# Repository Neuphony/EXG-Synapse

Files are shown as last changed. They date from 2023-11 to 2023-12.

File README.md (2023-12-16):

<h1 id="github---readme">Github - Readme</h1>
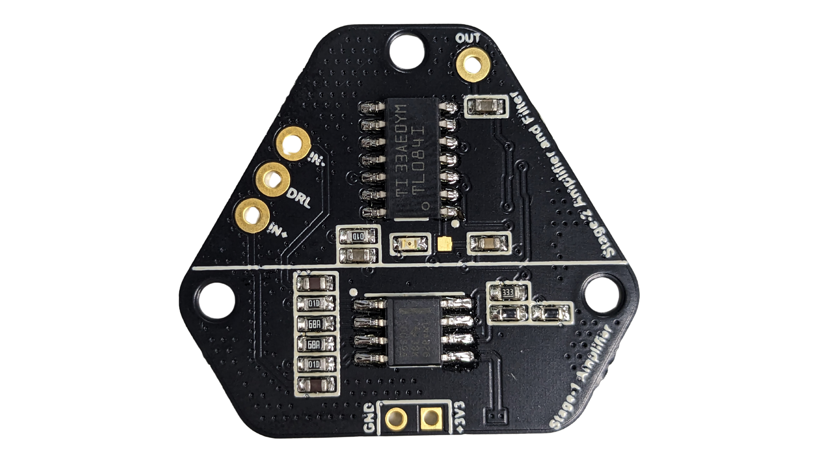
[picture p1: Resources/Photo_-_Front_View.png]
front
<p>Front View<br>        </p>
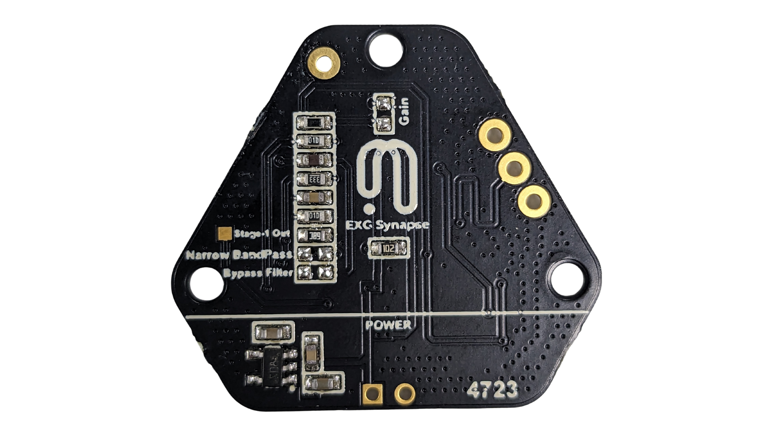
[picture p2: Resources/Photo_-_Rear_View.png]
rear
<p>Rear View<br>        </p>
<p><strong>Setup Instructions</strong></p>
<ol>
<li><p><strong>What is EXG Synapse?</strong>  </p>
<p>  Neuphony EXG Synapse is an innovative, hexagon-shaped chip designed for recording high-quality biopotential signals from various regions of the body, including the heart (ECG), brain (EEG), eyes (EOG), and muscles (EMG). Serving as a robust analog-front-end (AFE) biopotential signal-acquisition board, the Neuphony EXG Synapse can seamlessly integrate with a range of microcontroller units (MCUs) or single-board computers (SBCs) equipped with an analog-to-digital converter (ADC). Compatible platforms include popular options such as Arduino UNO &amp; Nano, Espressif ESP32 and more.</p>
</li>
<li><p><strong>Hardware Requirements</strong> :   EXG Synapse, DOIT-ESP32-DEVKIT-V1, Jumper Wires<br><strong>Software Requirements</strong> : Arduino IDE</p>
</li>
<li><p><strong>PCB Configuration</strong>  </p>
<p>  EXG Synapse has configuration options in terms of gain and bandpass filter bandwidth. The user can modify these values depending on the use case. Here is an image showing the resistor pad R9(for gain) and capacitor pad C2(for filter bandwidth).</p>
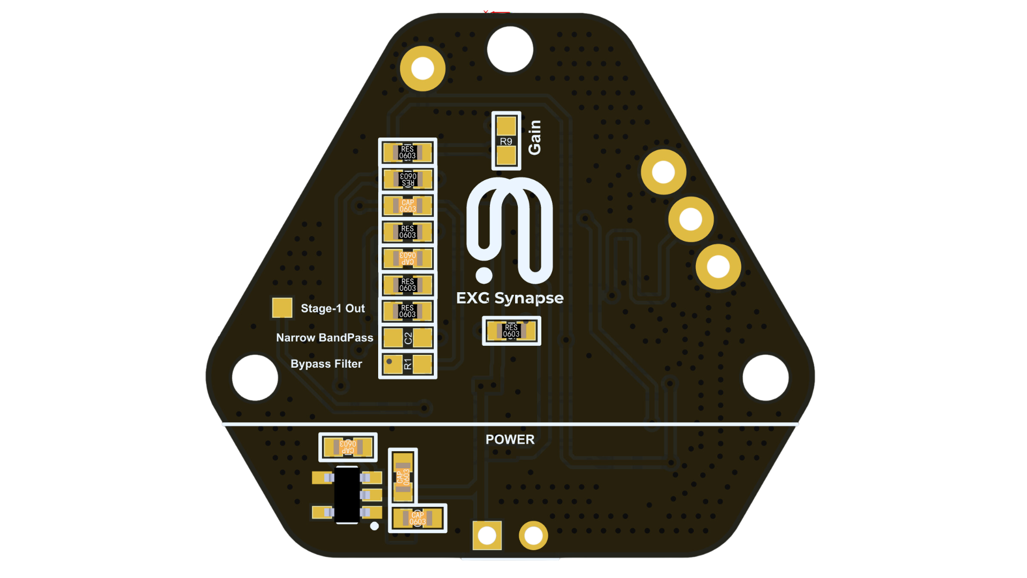
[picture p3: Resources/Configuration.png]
Configuration

</li>
<li><p><strong>Connection with ESP32</strong>  </p>
<p>  EXG Synapse requires only three wires to connect to any MCU. 3V3 connects to the 3V3 pin on the ESP32 and GND to GND pin on the ESP32. The Output of EXG Synapse can be connected to any ADC pin of ESP32 and configured as an analog input to read the data.</p>
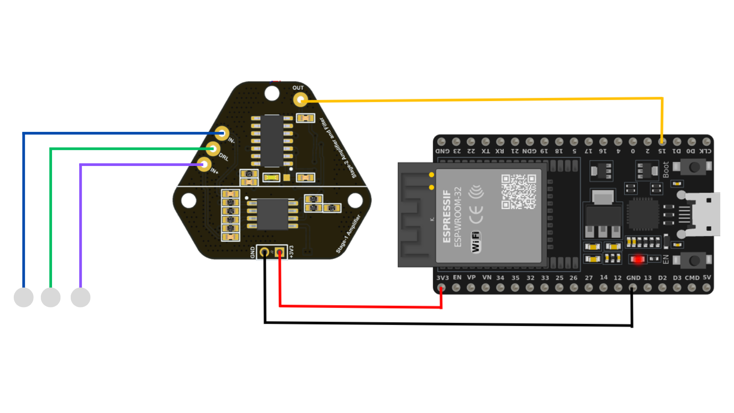
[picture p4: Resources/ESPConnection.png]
ESPConnection

</li>
<li><p><strong>Flashing Code on ESP32</strong>  </p>
<p>  To flash the required code on ESP32, you need to install Arduino IDE and setup for flashing to an ESP32. You can follow <a href="https://espressif-docs.readthedocs-hosted.com/projects/arduino-esp32/en/latest/installing.html">this guide</a> if you don’t find your board listed in Arduino. Once your board is added to Arduino, you can go to <a href="https://github.com/Neuphony/EXG-Synapse">our GitHub repository</a>, here you will find all the necessary files for acquiring the data using EXG Synapse.</p>
<p>  Navigate to the folder of your choice (serial or BLE), and download the required .ino (EEG, ECG, EMG, EOG). Now compile and upload the code on your board.</p>
<p>  Please follow the screenshots given below.</p>
<p>  <strong>Board selection:</strong></p>
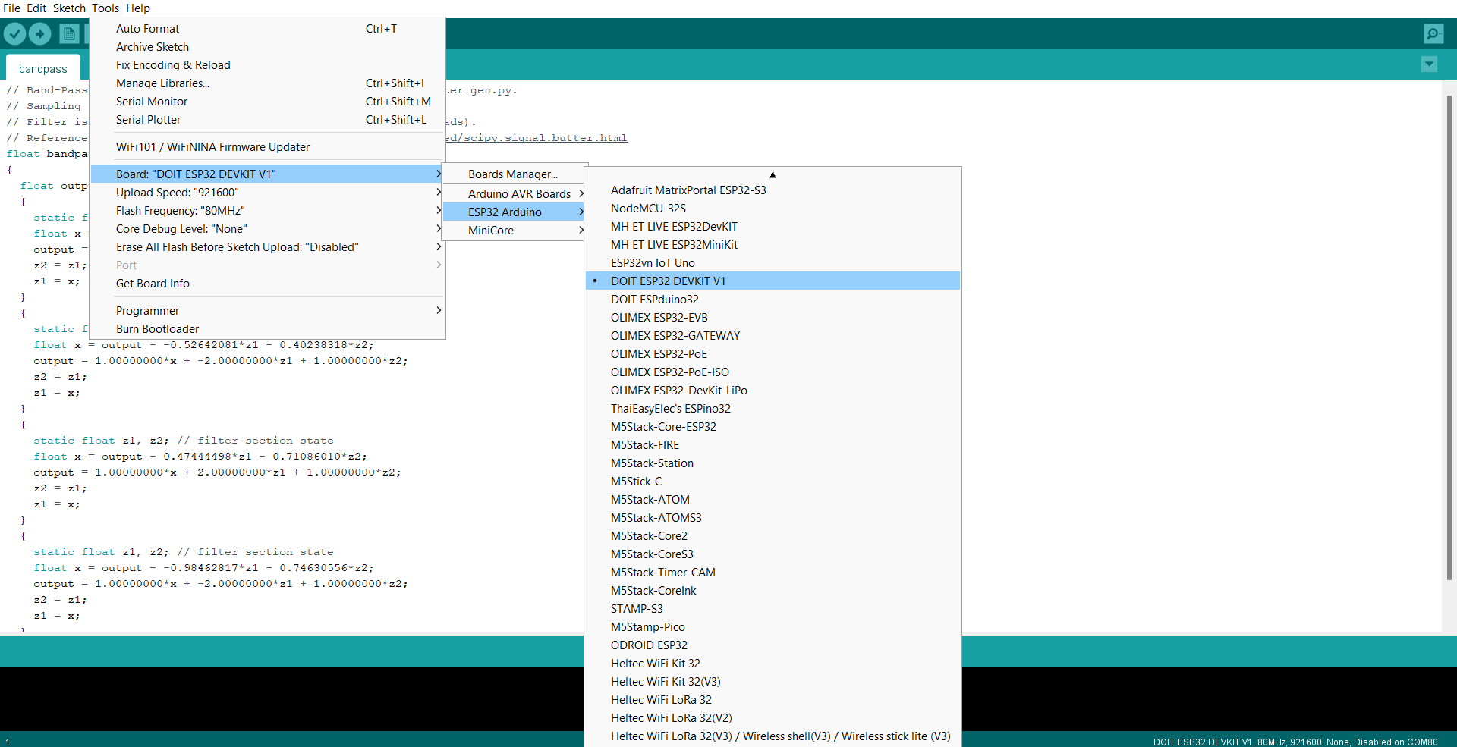
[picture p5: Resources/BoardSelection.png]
BoardSelectiond

<p>  <strong>COM Port selection:</strong></p>
<p>  BoardSelection</p>
</li>
<li><p><strong>Skin Preparation</strong>  </p>
<p>  Before placing the electrode, skin surface must be cleaned with an alcohol based wet wipe and then Nuprep Gel can be used to enhance the signal quality as it reduces the skin impedance. You can follow <a href="https://www.youtube.com/watch?v=qQSClWIYUwM&t=76s">this guide</a> on how to use Nuprep Gel while preparing for data acquisition.</p>
</li>
<li><p><strong>Data Visualization:</strong>  </p>
<p>  The Lab Streaming Layer (LSL) is a system designed for real-time data streaming and recording. We have provided a python script located in the <a href="https://github.com/Neuphony/EXG-Synapse">GitHub repository</a> used to read the data from serial and create a LSL stream. The stream created by the script can be easily visualized using a LSL-compatible software such as <strong><a href="https://pressrelease.brainproducts.com/lsl-viewer/">BrainVision LSL Viewer</a>.</strong> It can be downloaded for free using this <a href="https://www.brainproducts.com/downloads/more-software/#utilities">link</a>.</p>

# EEG

1. **What is EEG?**
EEG stands for electroencephalography, which is a non-invasive technique used to measure and record electrical activity in the brain. It involves placing electrodes on the scalp to detect and amplify the electrical signals produced by the brain. These signals, known as brainwaves, can provide insights into brain function and activity.

2. **What is EXG Synapse?**
Neuphony EXG Synapse is an innovative, hexagon-shaped chip designed for recording high-quality biopotential signals from various regions of the body, including the heart (ECG), brain (EEG), eyes (EOG), and muscles (EMG). Serving as a robust analog-front-end (AFE) biopotential signal-acquisition board, the Neuphony EXG Synapse can seamlessly integrate with a range of microcontroller units (MCUs) or single-board computers (SBCs) equipped with an analog-to-digital converter (ADC). Compatible platforms include popular options such as Arduino UNO & Nano, Espressif ESP32 and more.

3. **Hardware Requirements** : EXG Synapse, DOIT-ESP32-DEVKIT-V1, Jumper Wires
**Software Requirements** : Arduino IDE

4. **PCB Configuration:**
EXG Synapse has configuration options in terms of gain and bandpass filter bandwidth. The user can modify these values depending on the use case. Here is an image showing the resistor pad R9(for gain) and capacitor pad C2(for filter bandwidth).

    Configuration

1. **Connection with ESP32**
EXG Synapse requires only three wires to connect to any MCU. 3V3 connects to the 3V3 pin on the ESP32 and GND to GND pin on the ESP32. The Output of EXG Synapse can be connected to any ADC pin of ESP32 and configured as an analog input to read the data.

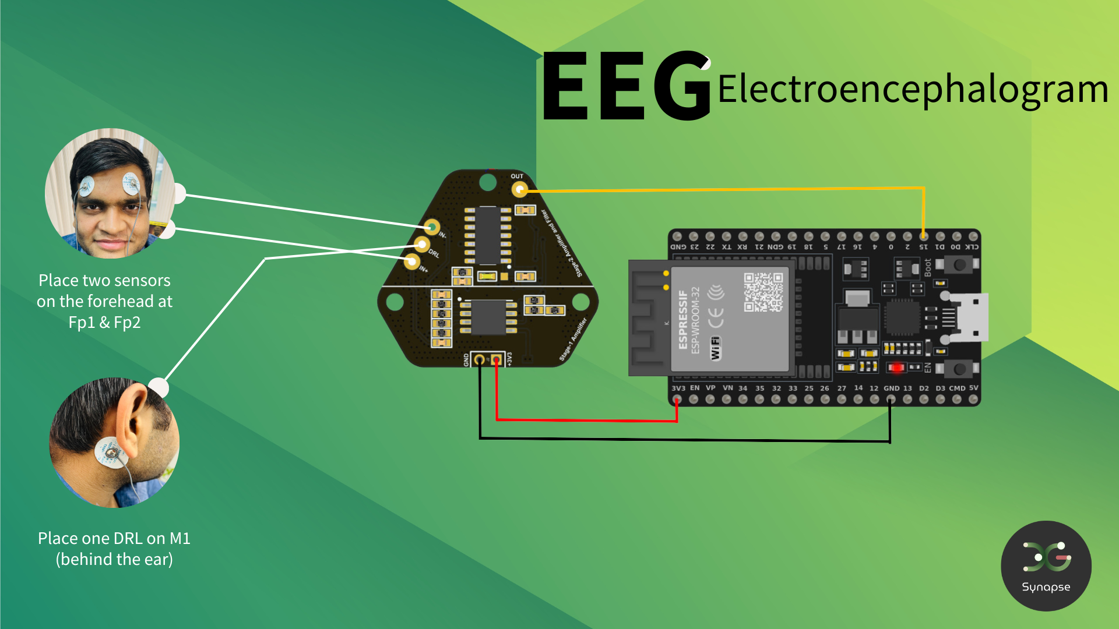
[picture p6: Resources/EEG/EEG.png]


1. **Flashing Code on ESP32**
To flash the required code on ESP32, you need to install Arduino IDE and setup for flashing to an ESP32. You can follow [this guide](https://espressif-docs.readthedocs-hosted.com/projects/arduino-esp32/en/latest/installing.html) if you don’t find your board listed in Arduino. Once your board is added to Arduino, you can go to [this GitHub repository](https://github.com/Neuphony/EXG-Synapse), here you will find all the necessary files for acquiring the data using EXG Synapse.

Navigate to the EEG folder and then to Arduino, and download required .ino file. Now compile and upload the code on your board.

2. **Skin Preparation**
Before placing the electrode, skin surface must be cleaned with an alcohol based wet wipe and then Nuprep Gel can be used to enhance the signal quality as it reduces the skin impedance. You can follow [this](https://www.youtube.com/watch?v=qQSClWIYUwM) guide on how to use Nuprep Gel while preparing for data acquisition.

3. **Electrode Placement:**
Check above image for correct electrode placement

4. **Data Visualization:**
Serial : The Lab Streaming Layer (LSL) is a system designed for real-time data streaming and recording. We have provided a python script located in the [GitHub repository](https://github.com/Neuphony/EXG-Synapse) used to read the data from serial and create a LSL stream. The stream created by the script can be easily visualized using a LSL-compatible software such as **[BrainVision LSL Viewer](https://pressrelease.brainproducts.com/lsl-viewer/).** It can be downloaded for free using this [link](https://www.brainproducts.com/downloads/more-software/#utilities).

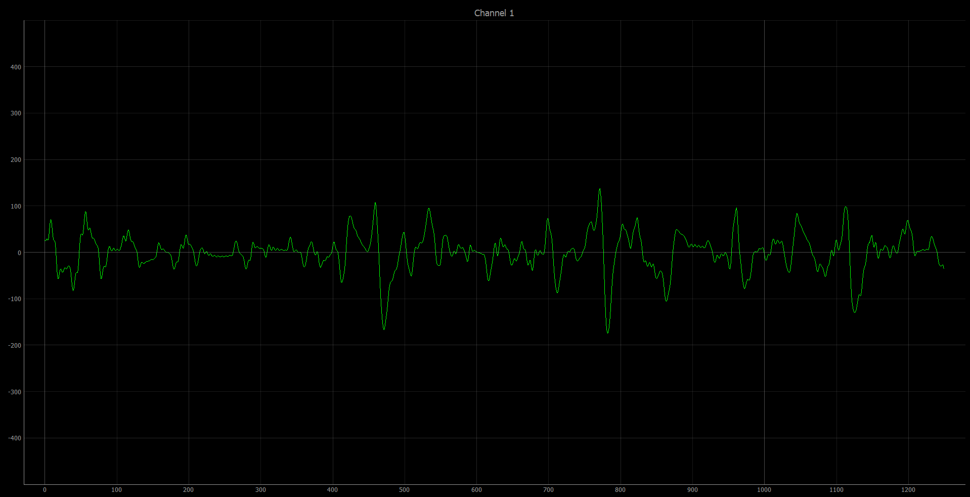
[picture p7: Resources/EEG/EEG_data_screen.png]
EEG_data_screen
    
    
    BLE : If flashed with the code provided under software\Arduino\ble, ESP32 will stream data continously over BLE. You can create a client side interface to read this data and use it for further applications.

# ECG

1. **What is ECG?**
ECG stands for Electrocardiogram. It is a medical test that measures and records the electrical activity of the heart. The ECG helps in diagnosing various heart conditions and evaluating the heart's overall health.

1. **What is EXG Synapse?**
Neuphony EXG Synapse is an innovative, hexagon-shaped chip designed for recording high-quality biopotential signals from various regions of the body, including the heart (ECG), brain (EEG), eyes (EOG), and muscles (EMG). Serving as a robust analog-front-end (AFE) biopotential signal-acquisition board, the Neuphony EXG Synapse can seamlessly integrate with a range of microcontroller units (MCUs) or single-board computers (SBCs) equipped with an analog-to-digital converter (ADC). Compatible platforms include popular options such as Arduino UNO & Nano, Espressif ESP32 and more.

2. **Hardware Requirements** : EXG Synapse, DOIT-ESP32-DEVKIT-V1, Jumper Wires
**Software Requirements** : Arduino IDE

3. **PCB Configuration:**
EXG Synapse has configuration options in terms of gain and bandpass filter bandwidth. The user can modify these values depending on the use case. Here is an image showing the resistor pad R9(for gain) and capacitor pad C2(for filter bandwidth).

Configuration

1. **Connection with ESP32**
EXG Synapse requires only three wires to connect to any MCU. 3V3 connects to the 3V3 pin on the ESP32 and GND to GND pin on the ESP32. The Output of EXG Synapse can be connected to any ADC pin of ESP32 and configured as an analog input to read the data.

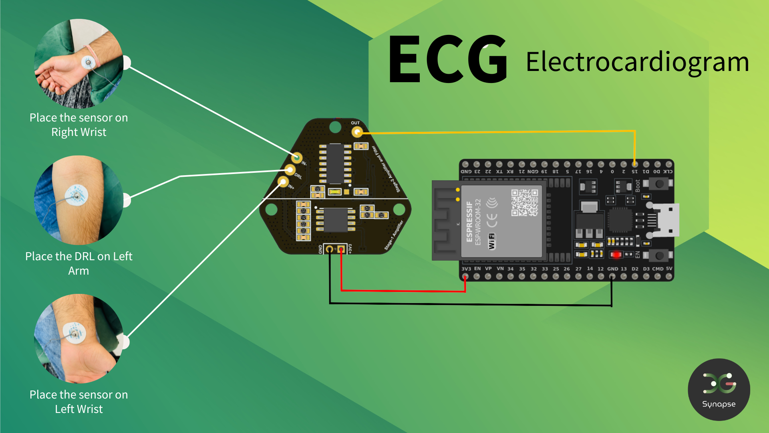
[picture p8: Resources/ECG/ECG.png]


1. **Flashing Code on ESP32**
To flash the required code on ESP32, you need to install Arduino IDE and setup for flashing to an ESP32. You can follow [this guide](https://espressif-docs.readthedocs-hosted.com/projects/arduino-esp32/en/latest/installing.html) if you don’t find your board listed in Arduino. Once your board is added to Arduino, you can go to [this GitHub repository](https://github.com/Neuphony/EXG-Synapse), here you will find all the necessary files for acquiring the data using EXG Synapse.
Navigate to the EEG folder and then to Arduino, and download required .ino file. Now compile and upload the code on your board.

2. **Skin Preparation**
Before placing the electrode, skin surface must be cleaned with an alcohol based wet wipe and then Nuprep Gel can be used to enhance the signal quality as it reduces the skin impedance. You can follow [this](https://www.youtube.com/watch?v=qQSClWIYUwM) guide on how to use Nuprep Gel while preparing for data acquisition.

3. **Electrode Placement:**
Check above image for correct electrode placement

1. **Data Visualization:**
Serial : The Lab Streaming Layer (LSL) is a system designed for real-time data streaming and recording. We have provided a python script located in the [GitHub repository](https://github.com/Neuphony/EXG-Synapse) used to read the data from serial and create a LSL stream. The stream created by the script can be easily visualized using a LSL-compatible software such as **[BrainVision LSL Viewer](https://pressrelease.brainproducts.com/lsl-viewer/).** It can be downloaded for free using this [link](https://www.brainproducts.com/downloads/more-software/#utilities).

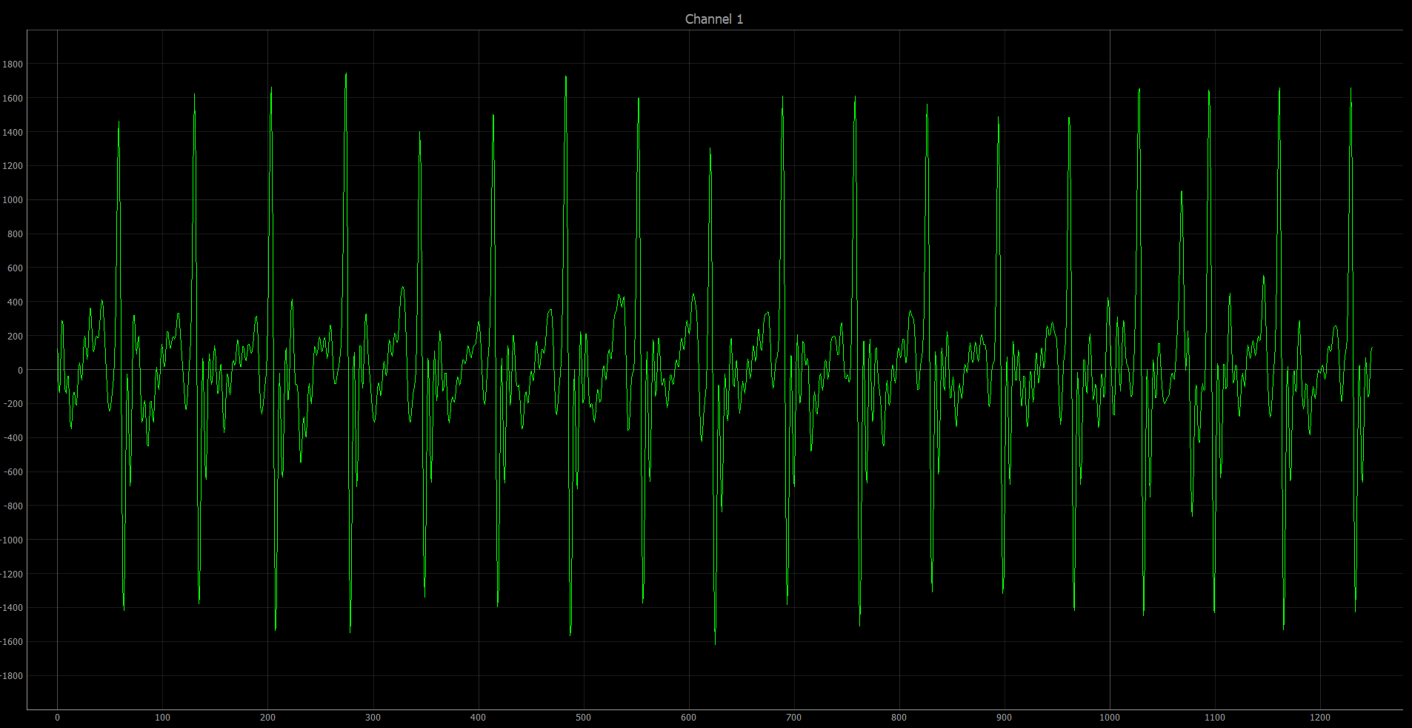
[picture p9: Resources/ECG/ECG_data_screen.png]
ECG_data_screen
    
    
    BLE : If flashed with the code provided under software\Arduino\ble, ESP32 will stream data continously over BLE. You can create a client side interface to read this data and use it for further applications.

# EMG

1. **What is EMG?**
    
    EMG stands for Electromyography. It is a technique used to measure and record the electrical activity produced by skeletal muscles. This information can be useful in various applications, such as studying muscle function, diagnosing neuromuscular disorders, and monitoring muscle activity during physical therapy or athletic training.
    
2. **What is EXG Synapse?**
Neuphony EXG Synapse is an innovative, hexagon-shaped chip designed for recording high-quality biopotential signals from various regions of the body, including the heart (ECG), brain (EEG), eyes (EOG), and muscles (EMG). Serving as a robust analog-front-end (AFE) biopotential signal-acquisition board, the Neuphony EXG Synapse can seamlessly integrate with a range of microcontroller units (MCUs) or single-board computers (SBCs) equipped with an analog-to-digital converter (ADC). Compatible platforms include popular options such as Arduino UNO & Nano, Espressif ESP32 and more.

3. **Hardware Requirements** : EXG Synapse, DOIT-ESP32-DEVKIT-V1, Jumper Wires
**Software Requirements** : Arduino IDE

4. **PCB Configuration:**
EXG Synapse has configuration options in terms of gain and bandpass filter bandwidth. The user can modify these values depending on the use case. Here is an image showing the resistor pad R9(for gain) and capacitor pad C2(for filter bandwidth).

Configuration

1. **Connection with ESP32**
EXG Synapse requires only three wires to connect to any MCU. 3V3 connects to the 3V3 pin on the ESP32 and GND to GND pin on the ESP32. The Output of EXG Synapse can be connected to any ADC pin of ESP32 and configured as an analog input to read the data.

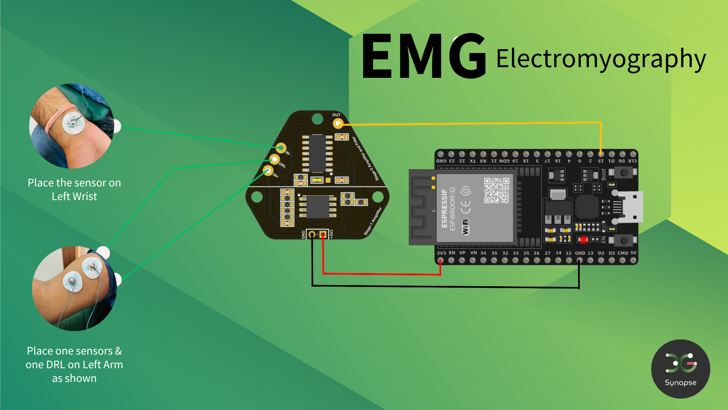
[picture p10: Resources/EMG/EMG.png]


1. **Flashing Code on ESP32**
To flash the required code on ESP32, you need to install Arduino IDE and setup for flashing to an ESP32. You can follow [this guide](https://espressif-docs.readthedocs-hosted.com/projects/arduino-esp32/en/latest/installing.html) if you don’t find your board listed in Arduino. Once your board is added to Arduino, you can go to [this GitHub repository](https://github.com/Neuphony/EXG-Synapse), here you will find all the necessary files for acquiring the data using EXG Synapse.
Navigate to the EMG folder and then to Arduino, and download required .ino file. Now compile and upload the code on your board.

2. **Skin Preparation**
Before placing the electrode, skin surface must be cleaned with an alcohol based wet wipe and then Nuprep Gel can be used to enhance the signal quality as it reduces the skin impedance. You can follow [this](https://www.youtube.com/watch?v=qQSClWIYUwM) guide on how to use Nuprep Gel while preparing for data acquisition.

3. **Electrode Placement**
    
    Check above image for correct electrode placement
    
4. **Data Visualization:**
Serial : The Lab Streaming Layer (LSL) is a system designed for real-time data streaming and recording. We have provided a python script located in the [GitHub repository](https://github.com/Neuphony/EXG-Synapse) used to read the data from serial and create a LSL stream. The stream created by the script can be easily visualized using a LSL-compatible software such as **[BrainVision LSL Viewer](https://pressrelease.brainproducts.com/lsl-viewer/).** It can be downloaded for free using this [link](https://www.brainproducts.com/downloads/more-software/#utilities).

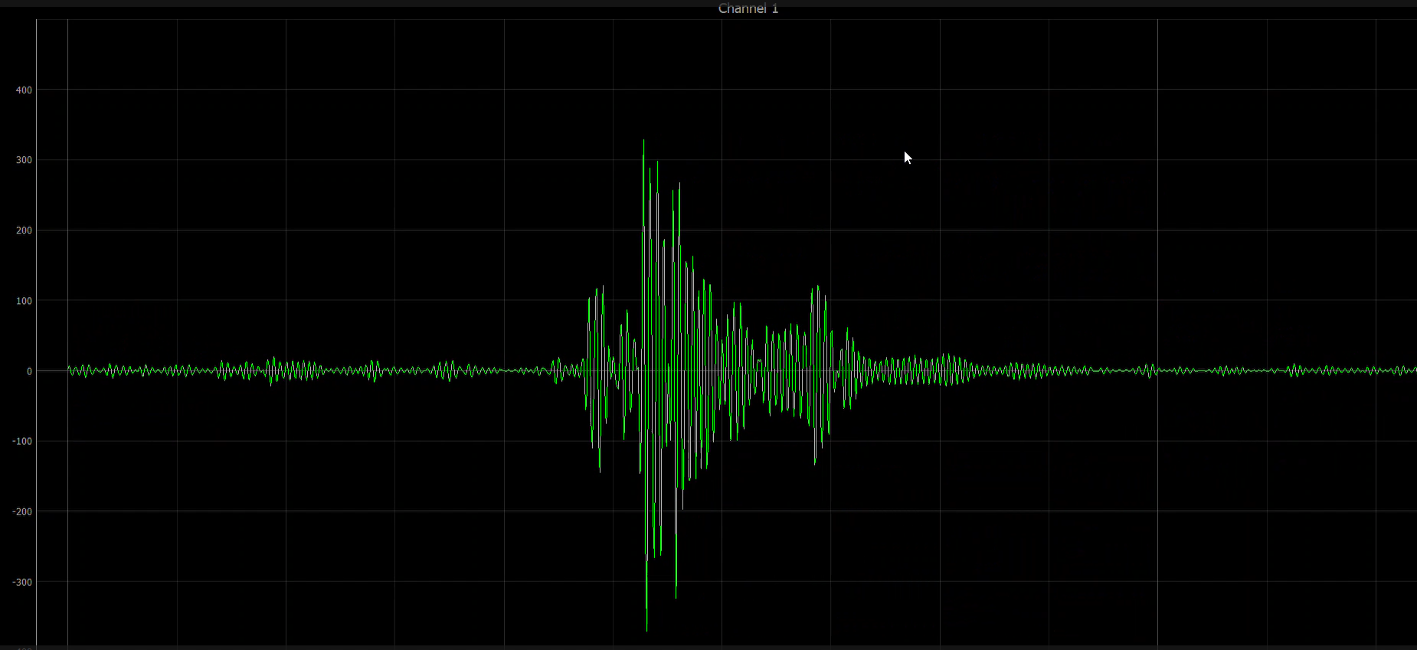
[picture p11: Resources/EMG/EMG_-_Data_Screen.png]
EMG - Data Screen.png
    
    
    BLE : If flashed with the code provided under software\Arduino\emg\ble, ESP32 will stream data continously over BLE. You can create a client side interface to read this data and use it for further applications.

# EOG

1. **What is EOG?**
    
    EOG stands for "Electrooculography." It refers to a technique used to measure and record the electrical activity of the muscles that control eye movements. This technique is often used in medical and research settings to study eye movements and diagnose certain eye disorders.
    
2. **What is EXG Synapse?**
Neuphony EXG Synapse is an innovative, hexagon-shaped chip designed for recording high-quality biopotential signals from various regions of the body, including the heart (ECG), brain (EEG), eyes (EOG), and muscles (EMG). Serving as a robust analog-front-end (AFE) biopotential signal-acquisition board, the Neuphony EXG Synapse can seamlessly integrate with a range of microcontroller units (MCUs) or single-board computers (SBCs) equipped with an analog-to-digital converter (ADC). Compatible platforms include popular options such as Arduino UNO & Nano, Espressif ESP32 and more.

3. **Hardware Requirements** : EXG Synapse, DOIT-ESP32-DEVKIT-V1, Jumper Wires
**Software Requirements** : Arduino IDE

4. **PCB Configuration:**
EXG Synapse has configuration options in terms of gain and bandpass filter bandwidth. The user can modify these values depending on the use case. Here is an image showing the resistor pad R9(for gain) and capacitor pad C2(for filter bandwidth).

Configuration

1. **Connection with ESP32**
EXG Synapse requires only three wires to connect to any MCU. 3V3 connects to the 3V3 pin on the ESP32 and GND to GND pin on the ESP32. The Output of EXG Synapse can be connected to any ADC pin of ESP32 and configured as an analog input to read the data. 

**Horizontal Eye Movements**

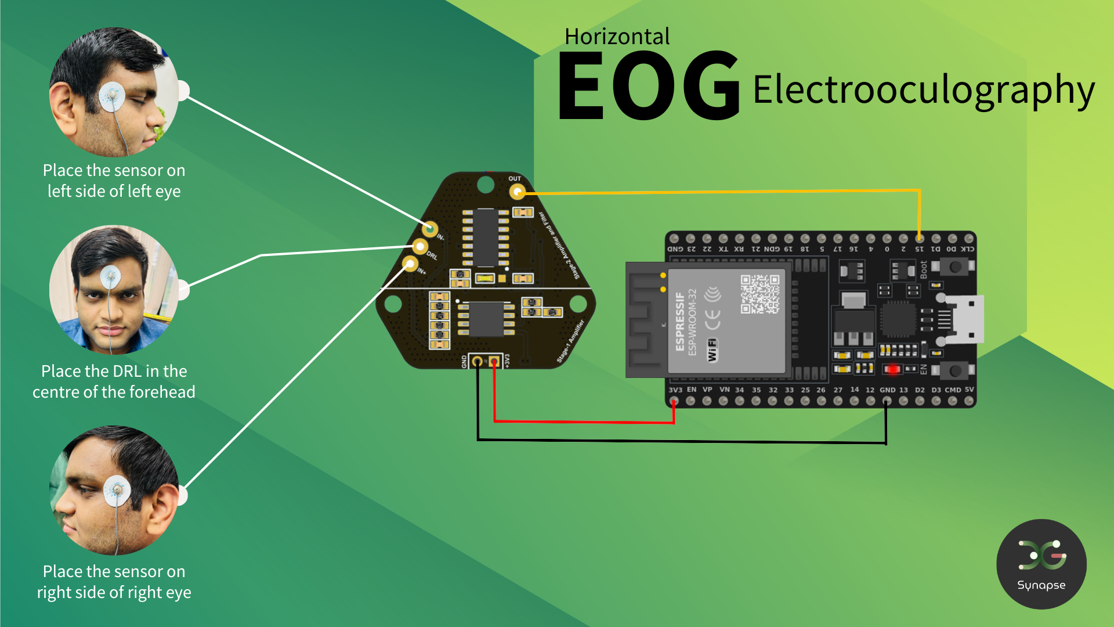
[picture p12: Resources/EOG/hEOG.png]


**Vertical Eye Movements**

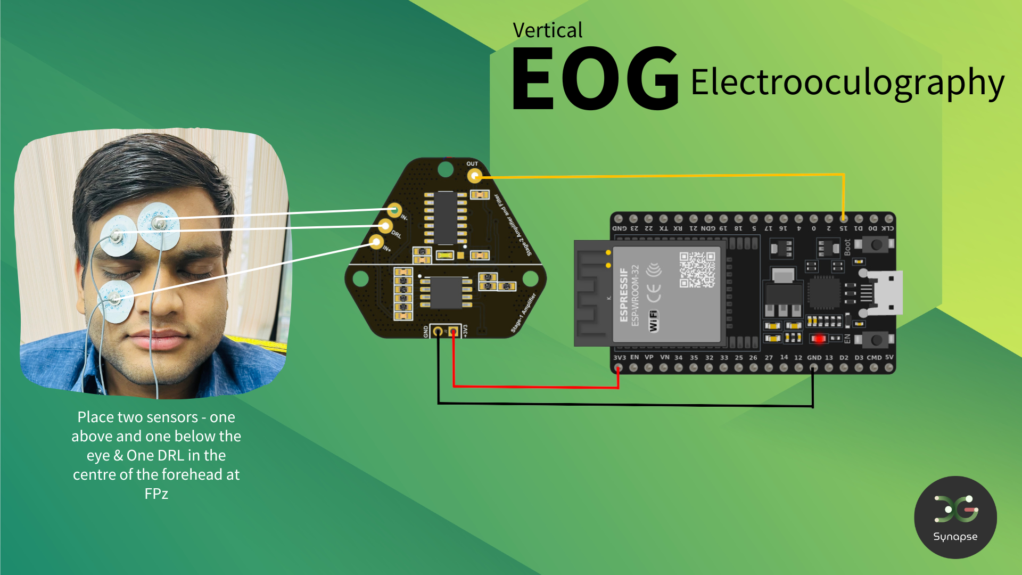
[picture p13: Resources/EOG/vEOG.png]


1. **Flashing Code on ESP32**
To flash the required code on ESP32, you need to install Arduino IDE and setup for flashing to an ESP32. You can follow [this guide](https://espressif-docs.readthedocs-hosted.com/projects/arduino-esp32/en/latest/installing.html) if you don’t find your board listed in Arduino. Once your board is added to Arduino, you can go to [this GitHub repository](https://github.com/Neuphony/EXG-Synapse), here you will find all the necessary files for acquiring the data using EXG Synapse.
Navigate to the EOG folder and then to Arduino, and download required .ino file. Now compile and upload the code on your board.

2. **Skin Preparation**
Before placing the electrode, skin surface must be cleaned with an alcohol based wet wipe and then Nuprep Gel can be used to enhance the signal quality as it reduces the skin impedance. You can follow [this](https://www.youtube.com/watch?v=qQSClWIYUwM) guide on how to use Nuprep Gel while preparing for data acquisition.

3. **Electrode Placement:**
Check above image for correct electrode placement

1. **Data Visualization:**
Serial : The Lab Streaming Layer (LSL) is a system designed for real-time data streaming and recording. We have provided a python script located in the [GitHub repository](https://github.com/Neuphony/EXG-Synapse) used to read the data from serial and create a LSL stream. The stream created by the script can be easily visualized using a LSL-compatible software such as **[BrainVision LSL Viewer](https://pressrelease.brainproducts.com/lsl-viewer/).** It can be downloaded for free using this [link](https://www.brainproducts.com/downloads/more-software/#utilities).

**Horizontal EOG Data**
    
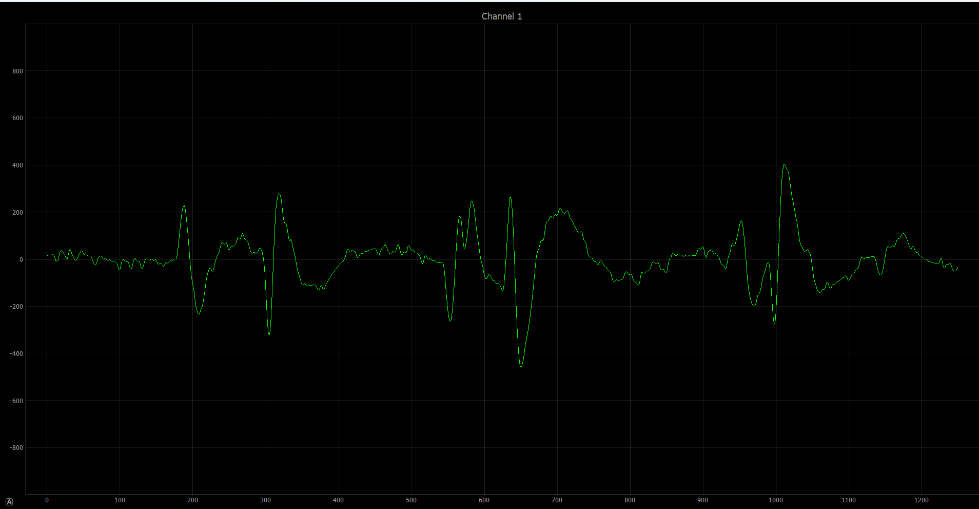
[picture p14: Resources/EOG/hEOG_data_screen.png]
hEOG_data_screen


**Vertical EOG Data**
    
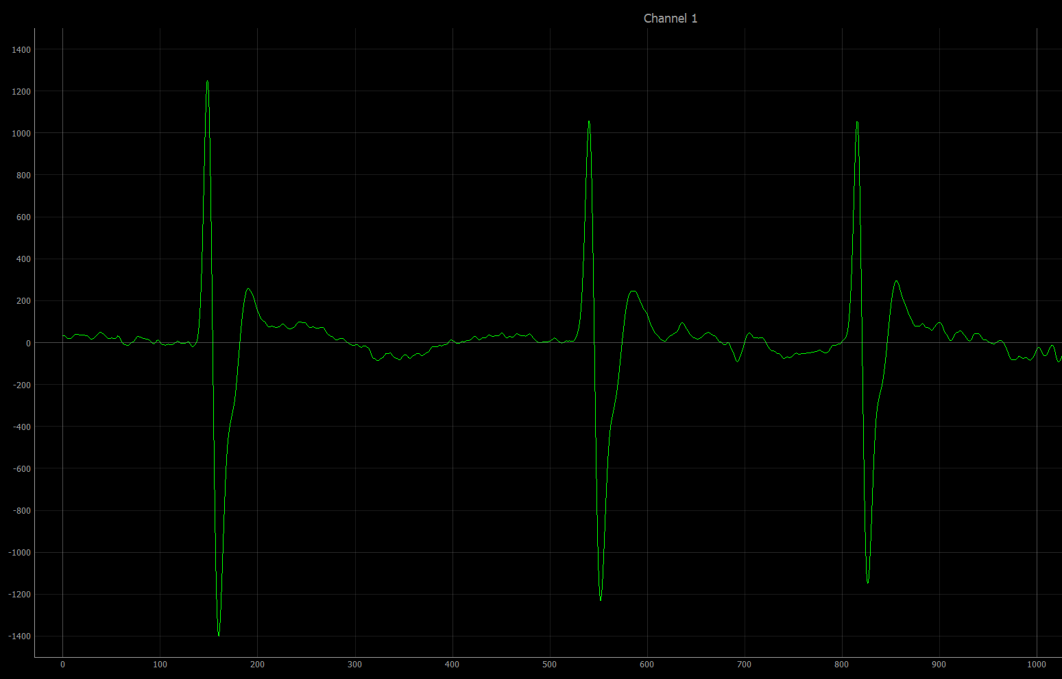
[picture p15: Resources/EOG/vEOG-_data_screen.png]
vEOG- data screen.png


BLE : If flashed with the code provided under software\Arduino\eog\ble, ESP32 will stream data continously over BLE. You can create a client side interface to read this data and use it for further applications.

</li>
</ol>
<p><strong>Dimensions</strong></p>
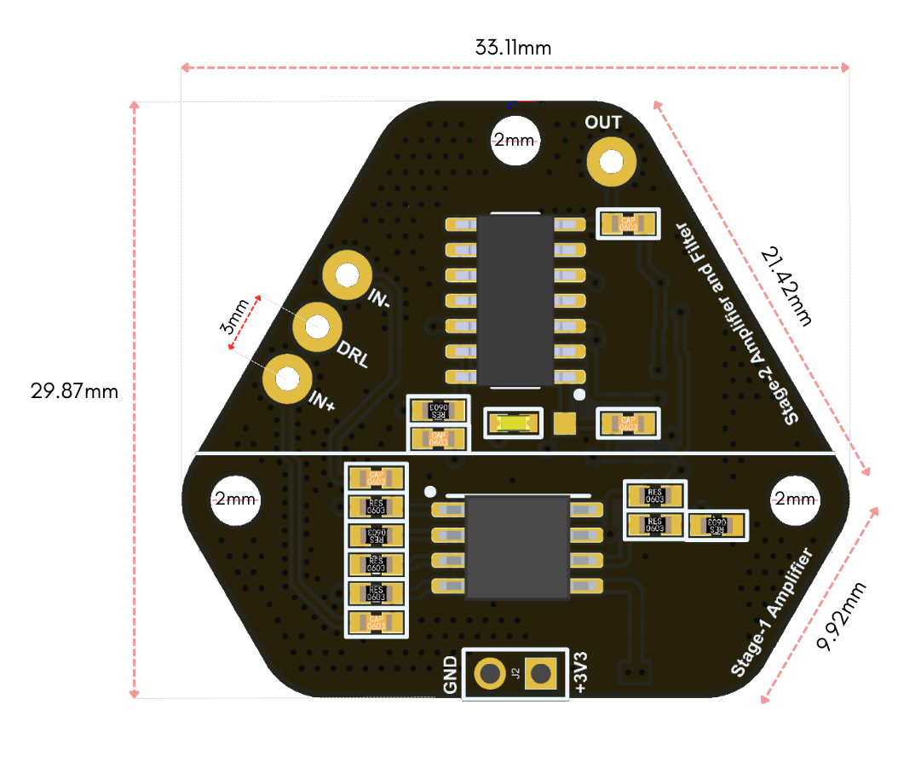
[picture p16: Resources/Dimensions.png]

<p><strong>Pinout</strong></p>
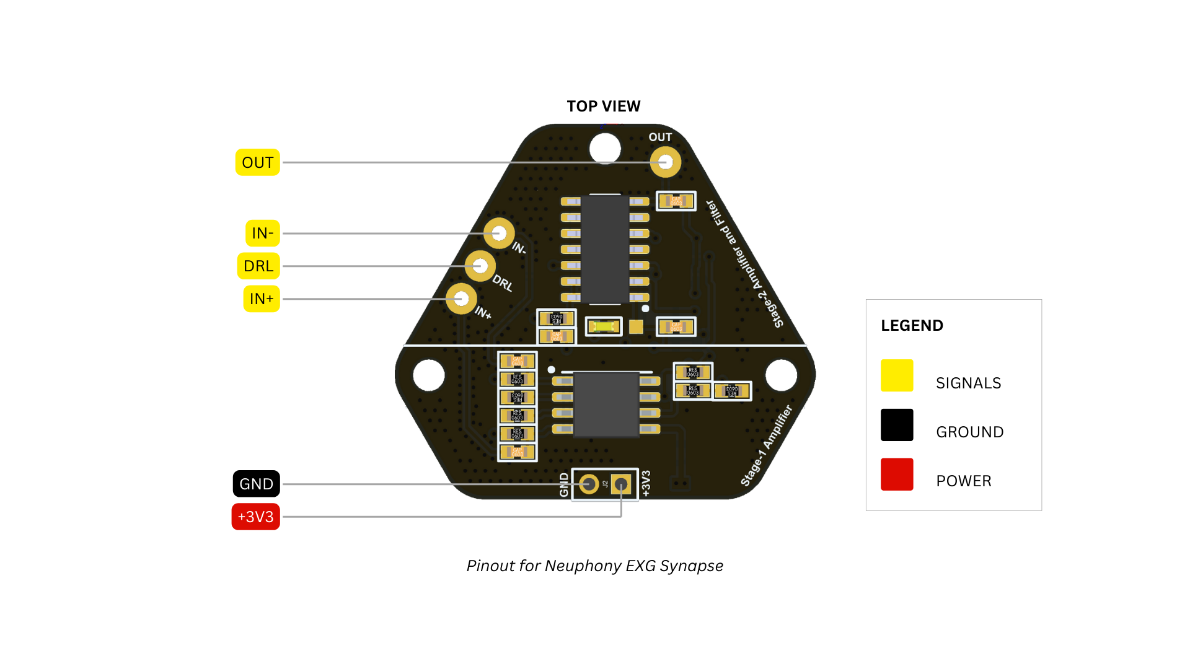
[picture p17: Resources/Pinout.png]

<p><strong>Schematic</strong></p>
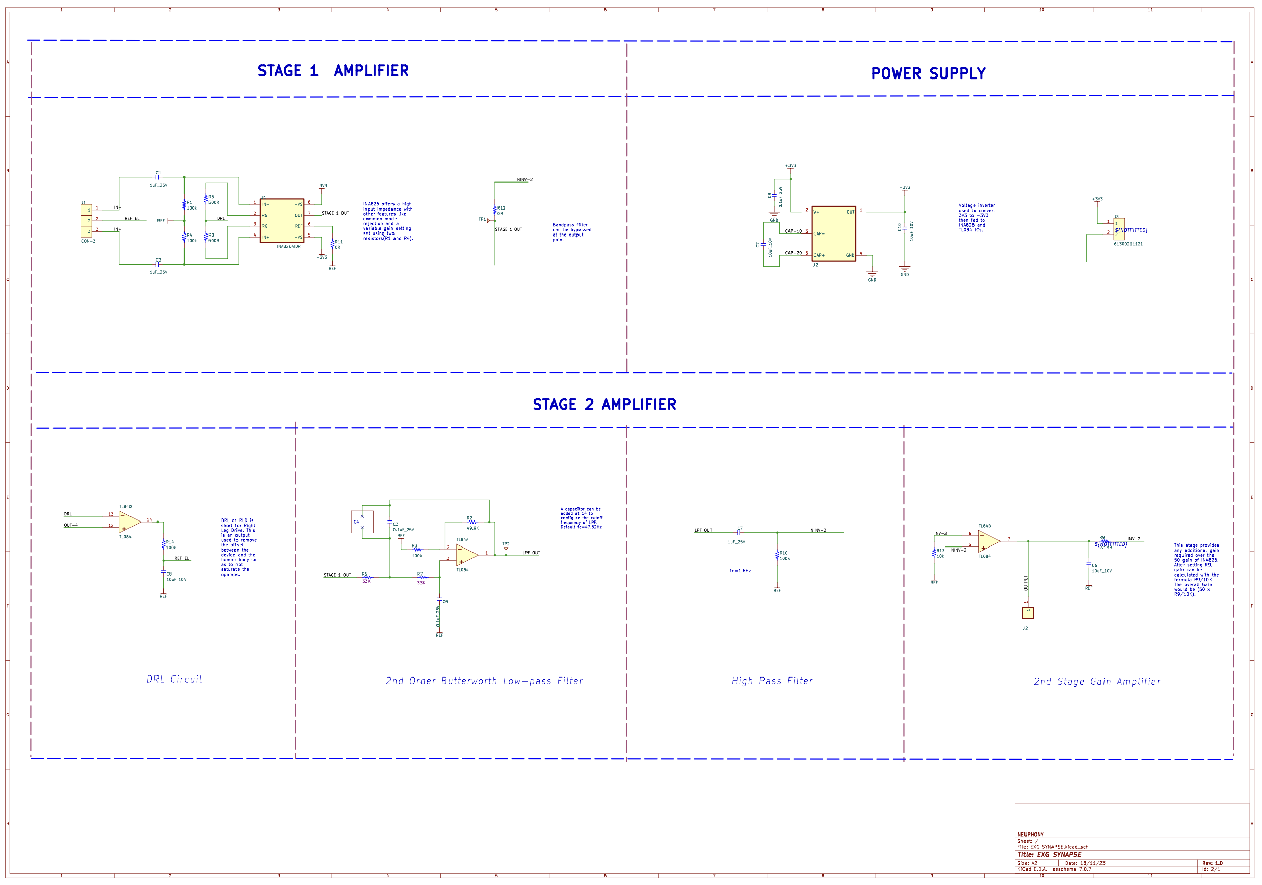
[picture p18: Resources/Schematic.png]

<p><strong>Licenses</strong>
Hardware - CERN-OHL-S-2.0
Software - MIT
Documentation - CC BY-SA 4.0</p>
<p>Certification - </p>
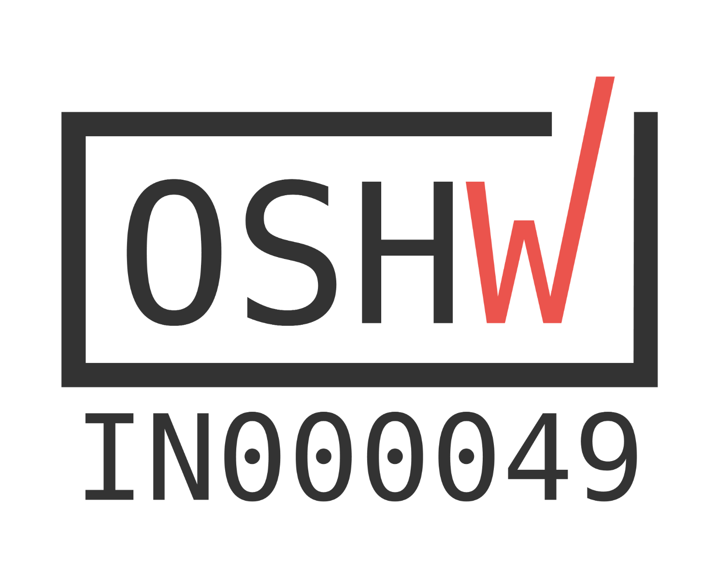
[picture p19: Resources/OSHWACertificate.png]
"Open
<p>&nbsp;&nbsp;&nbsp;&nbsp;&nbsp;&nbsp;&nbsp;&nbsp;&nbsp;&nbsp;&nbsp;&nbsp;<a href="License-Agreement-Synapse.md">Open Source Licenses Agreement</a></p>

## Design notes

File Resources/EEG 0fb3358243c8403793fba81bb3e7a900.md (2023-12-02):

# EEG

1. **What is EEG?**
EEG stands for electroencephalography, which is a non-invasive technique used to measure and record electrical activity in the brain. It involves placing electrodes on the scalp to detect and amplify the electrical signals produced by the brain. These signals, known as brainwaves, can provide insights into brain function and activity.

2. **What is EXG Synapse?**
Neuphony EXG Synapse is an innovative, hexagon-shaped chip designed for recording high-quality biopotential signals from various regions of the body, including the heart (ECG), brain (EEG), eyes (EOG), and muscles (EMG). Serving as a robust analog-front-end (AFE) biopotential signal-acquisition board, the Neuphony EXG Synapse can seamlessly integrate with a range of microcontroller units (MCUs) or single-board computers (SBCs) equipped with an analog-to-digital converter (ADC). Compatible platforms include popular options such as Arduino UNO & Nano, Espressif ESP32 and more.

3. **Hardware Requirements** : EXG Synapse, DOIT-ESP32-DEVKIT-V1, Jumper Wires
**Software Requirements** : Arduino IDE

4. **PCB Configuration:**
EXG Synapse has configuration options in terms of gain and bandpass filter bandwidth. The user can modify these values depending on the use case. Here is an image showing the resistor pad R9(for gain) and capacitor pad C2(for filter bandwidth).

    

1. **Connection with ESP32**
EXG Synapse requires only three wires to connect to any MCU. 3V3 connects to the 3V3 pin on the ESP32 and GND to GND pin on the ESP32. The Output of EXG Synapse can be connected to any ADC pin of ESP32 and configured as an analog input to read the data.



1. **Flashing Code on ESP32**
To flash the required code on ESP32, you need to install Arduino IDE and setup for flashing to an ESP32. You can follow [this guide](https://espressif-docs.readthedocs-hosted.com/projects/arduino-esp32/en/latest/installing.html) if you don’t find your board listed in Arduino. Once your board is added to Arduino, you can go to [this GitHub repository](https://github.com/Neuphony/EXG-Synapse), here you will find all the necessary files for acquiring the data using EXG Synapse.

Navigate to the EEG folder and then to Arduino, and download required .ino file. Now compile and upload the code on your board.

2. **Skin Preparation**
Before placing the electrode, skin surface must be cleaned with an alcohol based wet wipe and then Nuprep Gel can be used to enhance the signal quality as it reduces the skin impedance. You can follow [this](https://www.youtube.com/watch?v=qQSClWIYUwM) guide on how to use Nuprep Gel while preparing for data acquisition.

3. **Electrode Placement:**
Check above image for correct electrode placement

4. **Data Visualization:**
Serial : The Lab Streaming Layer (LSL) is a system designed for real-time data streaming and recording. We have provided a python script located in the [GitHub repository](https://github.com/Neuphony/EXG-Synapse) used to read the data from serial and create a LSL stream. The stream created by the script can be easily visualized using a LSL-compatible software such as **[BrainVision LSL Viewer](https://pressrelease.brainproducts.com/lsl-viewer/).** It can be downloaded for free using this [link](https://www.brainproducts.com/downloads/more-software/#utilities).

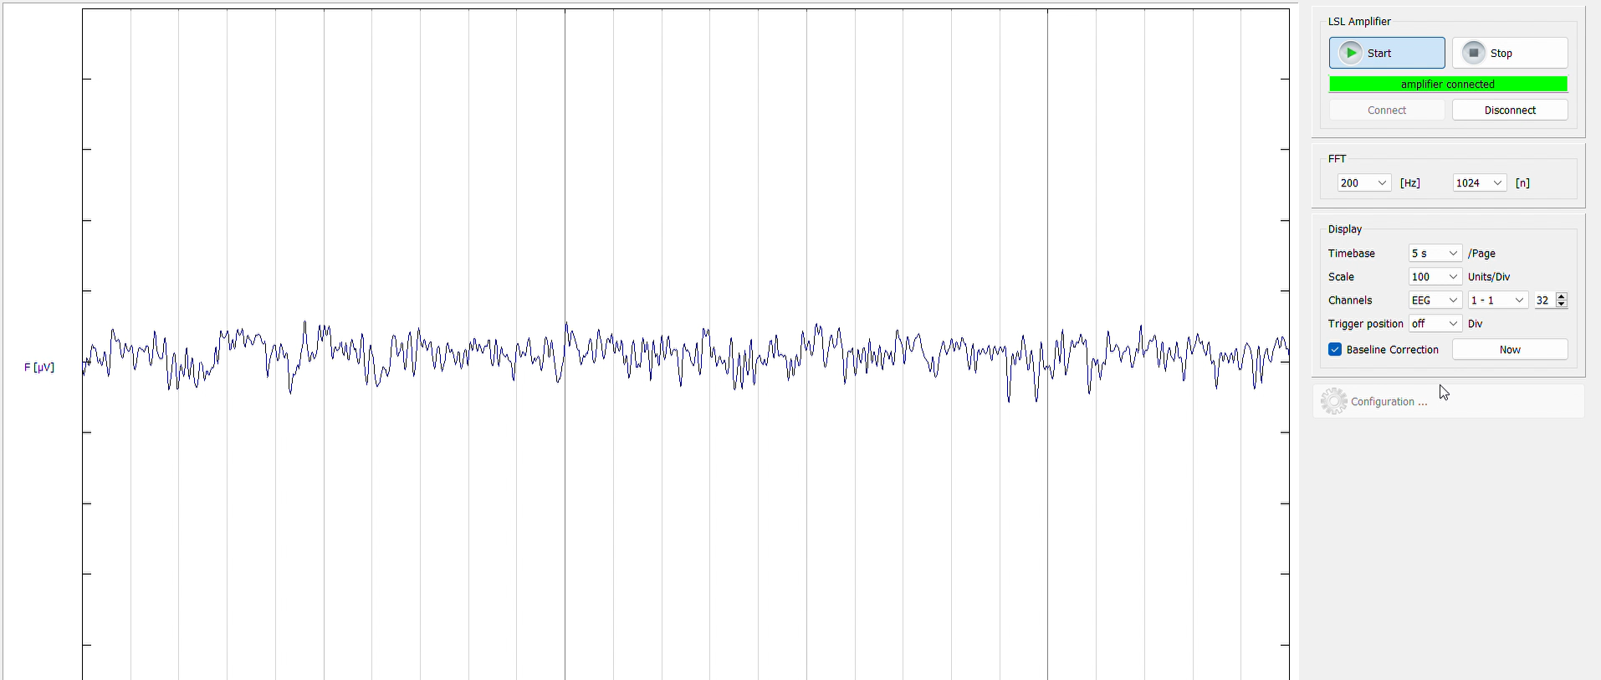
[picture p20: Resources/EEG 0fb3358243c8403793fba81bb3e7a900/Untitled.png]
    
    
    BLE : If flashed with the code provided under software\Arduino\ble, ESP32 will stream data continously over BLE. You can create a client side interface to read this data and use it for further applications.

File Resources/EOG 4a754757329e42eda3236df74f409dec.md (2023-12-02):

# EOG

1. **What is EOG?**
    
    EOG stands for "Electrooculography." It refers to a technique used to measure and record the electrical activity of the muscles that control eye movements. This technique is often used in medical and research settings to study eye movements and diagnose certain eye disorders.
    
2. **What is EXG Synapse?**
Neuphony EXG Synapse is an innovative, hexagon-shaped chip designed for recording high-quality biopotential signals from various regions of the body, including the heart (ECG), brain (EEG), eyes (EOG), and muscles (EMG). Serving as a robust analog-front-end (AFE) biopotential signal-acquisition board, the Neuphony EXG Synapse can seamlessly integrate with a range of microcontroller units (MCUs) or single-board computers (SBCs) equipped with an analog-to-digital converter (ADC). Compatible platforms include popular options such as Arduino UNO & Nano, Espressif ESP32 and more.

3. **Hardware Requirements** : EXG Synapse, DOIT-ESP32-DEVKIT-V1, Jumper Wires
**Software Requirements** : Arduino IDE

4. **PCB Configuration:**
EXG Synapse has configuration options in terms of gain and bandpass filter bandwidth. The user can modify these values depending on the use case. Here is an image showing the resistor pad R9(for gain) and capacitor pad C2(for filter bandwidth).



1. **Connection with ESP32**
EXG Synapse requires only three wires to connect to any MCU. 3V3 connects to the 3V3 pin on the ESP32 and GND to GND pin on the ESP32. The Output of EXG Synapse can be connected to any ADC pin of ESP32 and configured as an analog input to read the data. 

**Horizontal Eye Movements**



**Vertical Eye Movements**



1. **Flashing Code on ESP32**
To flash the required code on ESP32, you need to install Arduino IDE and setup for flashing to an ESP32. You can follow [this guide](https://espressif-docs.readthedocs-hosted.com/projects/arduino-esp32/en/latest/installing.html) if you don’t find your board listed in Arduino. Once your board is added to Arduino, you can go to [this GitHub repository](https://github.com/Neuphony/EXG-Synapse), here you will find all the necessary files for acquiring the data using EXG Synapse.
Navigate to the EOG folder and then to Arduino, and download required .ino file. Now compile and upload the code on your board.

2. **Skin Preparation**
Before placing the electrode, skin surface must be cleaned with an alcohol based wet wipe and then Nuprep Gel can be used to enhance the signal quality as it reduces the skin impedance. You can follow [this](https://www.youtube.com/watch?v=qQSClWIYUwM) guide on how to use Nuprep Gel while preparing for data acquisition.

3. **Electrode Placement:**
Check above image for correct electrode placement

1. **Data Visualization:**

Serial : The Lab Streaming Layer (LSL) is a system designed for real-time data streaming and recording. We have provided a python script located in the [GitHub repository](https://github.com/Neuphony/EXG-Synapse) used to read the data from serial and create a LSL stream. The stream created by the script can be easily visualized using a LSL-compatible software such as **[BrainVision LSL Viewer](https://pressrelease.brainproducts.com/lsl-viewer/).** It can be downloaded for free using this [link](https://www.brainproducts.com/downloads/more-software/#utilities).

**Horizontal EOG Data**
    
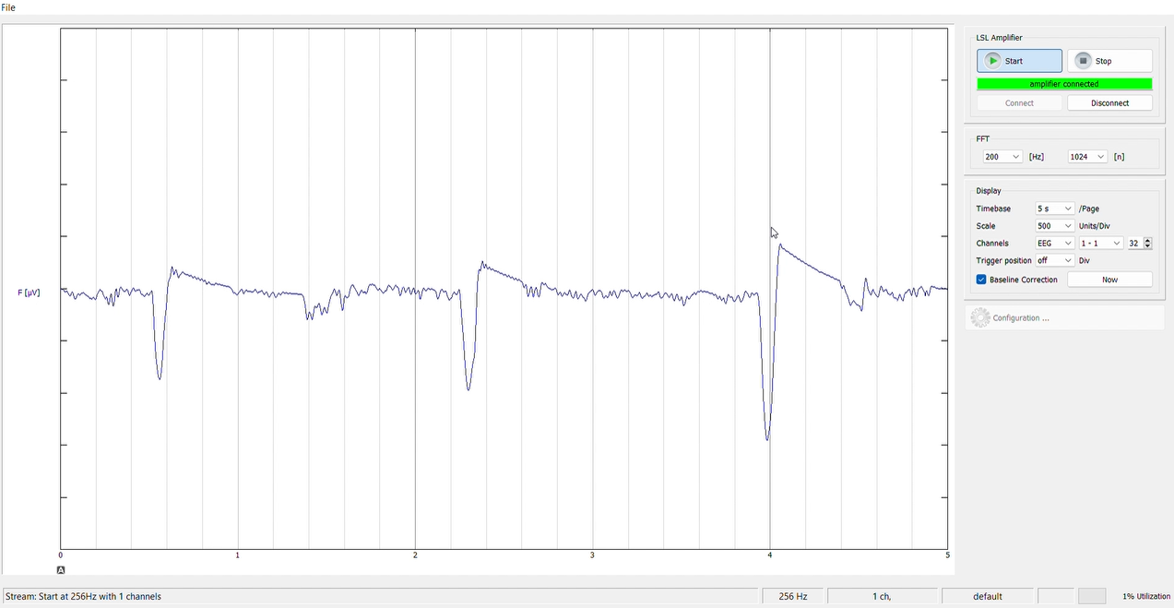
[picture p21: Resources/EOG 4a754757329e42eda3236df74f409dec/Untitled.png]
    
    
**Vertical EOG Data**
    
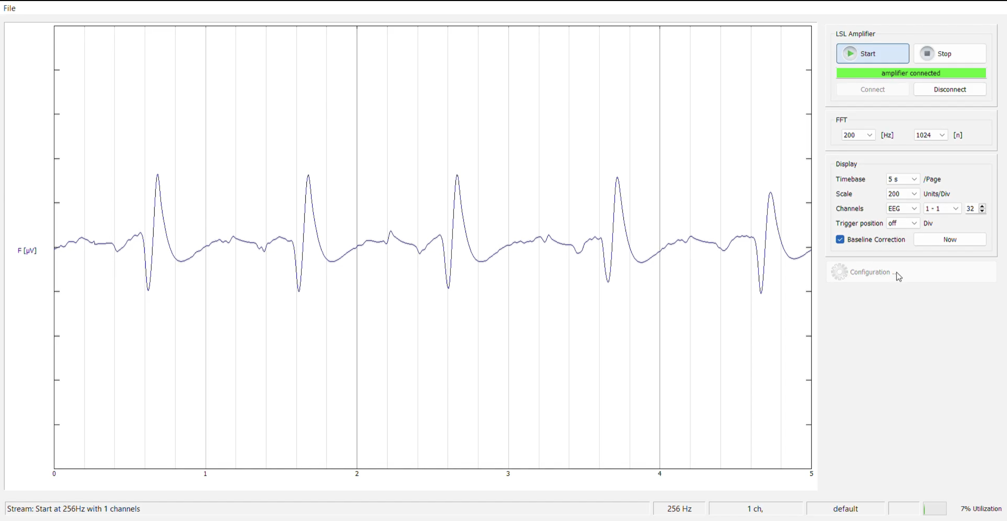
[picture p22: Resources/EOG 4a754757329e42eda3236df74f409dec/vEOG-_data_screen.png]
vEOG- data screen.png
    
    
    BLE : If flashed with the code provided under software\Arduino\eog\ble, ESP32 will stream data continously over BLE. You can create a client side interface to read this data and use it for further applications.

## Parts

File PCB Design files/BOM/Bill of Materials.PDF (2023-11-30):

Designator | Quantity | Manufacturer Part Number | Manufacturer | Description | Footprint | Comment
C1, C4, C7 | 3 CC0603KRX7R8BB105 | | Yageo | 1µF Multilayer Ceramic Capacitor MLCC 25 V; X7R Dielectric 0603 Surface Mount | C0603 | 1uF_25V
C3, C5, C9 | 3 TMK107BJ104KA-T | | Taiyo Yuden | 100nF Multilayer Ceramic Capacitor MLCC25 V; X7R Dielectric 0603 Surface Mount | C0603 | 0.1uF_25V
C6, C8, C10, C11 | 4 CL10A106KP8NNNC | | Samsung | Cap Ceramic 10uF 10V X5R 10% Pad SMD 0603 85C T/R | C0603 | 10uF_10V
D1 | 1 150060YS75000 | | Wurth Electronics | WURTH ELEKTRONIK - 150060YS75000 - LED, Yellow, SMD, 0603, 30mA, 2 V, 590 nm | LED0603_Yellow | LED0603_30mA_2 V_YELLOW
R2 | 1 RC0603FR-0749K9L | | Yageo | SMD Chip Resistor, 49.9 kOhm, ± 1%, 100mW, 0603 [1608 Metric], Thick Film, General Purpose | R0603 | 49.9K
R3, R5, R10, R11, R14 | 5 RMCF0603FT100K | | Stackpole Electronics | RES 100K OHM 1% 1/10W 0603 | R0603 | 100k
R4, R12 | 2 RC0603FR-07499RL | | Yageo | Res Thick Film 0603 499Ohm 1% 1/10W ±100ppm/°C Molded SMD Paper T/R | R0603 | 500R
R6, R7 | 2 ERJ-3EKF3302V | | Panasonic | Res Thick Film 0603 33K Ohm 1% 0.1W(1/10W) ±100ppm/C Pad SMD Automotive T/R | R0603 | 33K
R8, R17 | 2 CRCW0603-0000Z0EA | | Vishay | RES SMD 0OHM JUMPER 1/10W 0603 | R0603 | 0R
R13 | 1 ERJ-3EKF1002V | | Panasonic | Res Thick Film 0603 10K Ohm 1% 1/10W ±100ppm/°C Molded SMD Punched Carrier T/R | R0603 | 10k
R15 | 1 RMCF0603FT1K00 | | Stackpole Electronics | RES SMD 1K OHM 1% 1/10W 0603 | R0603 | 1K
U1 | 1 TL084IDR | | Texas Instruments | IC OPAMP JFET 3MHZ 14SOIC | SOIC14 | TL084IDR
U2 | 1 INA826AIDR | | Texas Instruments | Precision, 200-μA Supply Current, 36-V Supply Instrumentation Amplifier 8-SOIC -40 to 125 | SOIC-8_WINBOND | INA826AIDR
U3 | 1 LM828M5X/NOPB | | TI National Semiconductor | Switched Capacitor Voltage Converter 5-SOT-23 -40 to 85 | SOT23-5 | LM828M5X/NOPB

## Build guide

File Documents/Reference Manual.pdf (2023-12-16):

SYNAPSE

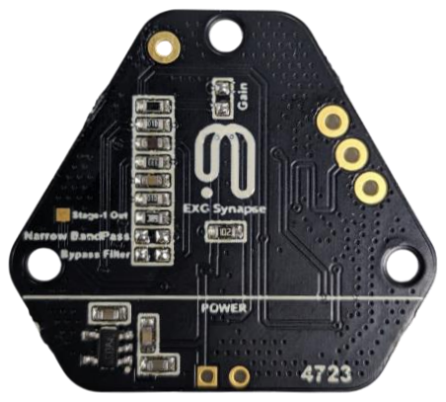
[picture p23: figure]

1 / 24 | SYNAPSE | Modified: 1/12/2023

Copyright 2023 © Pankhtech India Private Limited. All Rights Reserved

Product Reference Manual

Revision 2

## Introduction

Neuphony EXG Synapse is an innovative, hexagon-shaped chip designed for recording high-quality biopotential signals from various regions of the body, including the heart (ECG), brain (EEG), eyes (EOG), and muscles (EMG). Serving as a robust analog-front-end (AFE) biopotential signal-acquisition board, the Neuphony EXG Synapse can seamlessly integrate with a range of microcontroller units (MCUs) or single-board computers (SBCs) equipped with an analog-to-digital converter (ADC). Compatible platforms include popular options such as Arduino UNO & Nano, Espressif ESP32 and more.

This versatile device also interfaces effortlessly with dedicated ADCs like the Texas Instruments ADS1115 and ADS131M0x, expanding its compatibility and flexibility for diverse applications. The Neuphony EXG Synapse empowers users to explore and capture publication-grade biopotential signals, making it a valuable tool for researchers, developers, and enthusiasts in the field of bioelectronics and health monitoring.

2 / 24 | SYNAPSE | Modified: 1/12/2023

## CONTENTS

1. Features
2. Block Diagram
3. The Board

3.1 Top View

3.2 Bottom View

4. Specifications
5. Absolute Maximum Ratings
6. Board Topology / Layers

6.1 Top Layer

6.2 Bottom Layer

6.3 Layer Stack-Up

7. Dimensions
8. Pinout

8.1 Pinout Diagram

8.2 Pin Description

9. Default Frequency Range
10. Getting Started
11. EXG Circuits

11.1 EEG

11.2 ECG

11.3 EOG (Horizontal and Vertical)

11.4 EMG

12. Possible Configurations

12.1 Configurable Gain

12.2 Bandpass Filters Bandwidth

12.3 Bypass Bandpass Filter

13. Reference Documents
14. Certifications

14.1 Certification

14.2 Licenses

15. Company Information
16. Change Log

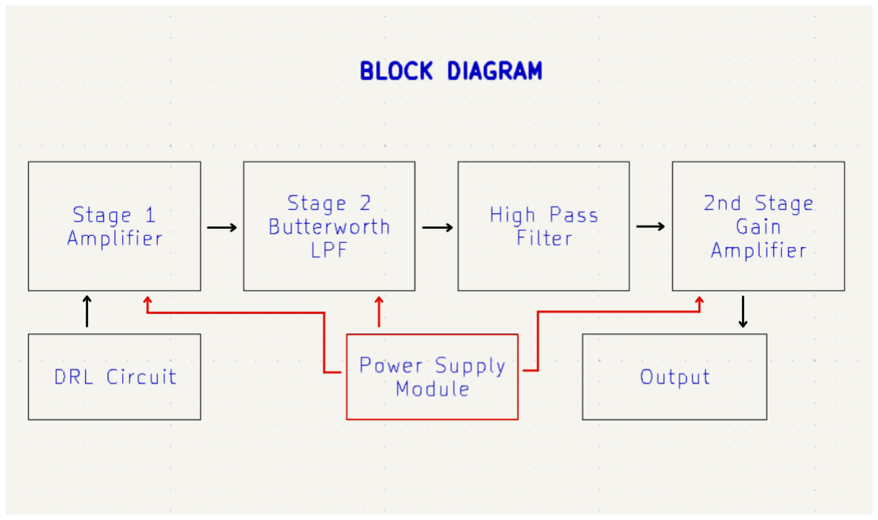
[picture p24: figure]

3 / 24 | SYNAPSE | Modified: 1/12/2023

## 1 Features

1. Comprehensive biopotential signal compatibility, covering ECG, EEG, EOG, and EMG, ensures a

versatile solution for various physiological monitoring applications.

2. Neuphony EXG Synapse offers customizable gain and filter bandwidth settings for precise signal

configuration.

3. Enjoy flexibility with an optional bypass of the bandpass filter, allowing tailored signal output for

diverse analysis.

4. Seamlessly pairs with any MCU featuring ADC, expanding compatibility across platforms like

Arduino, ESP32, STM32, and more.

5. Seamless Python/LSL compatibility

## 2 Block Diagram

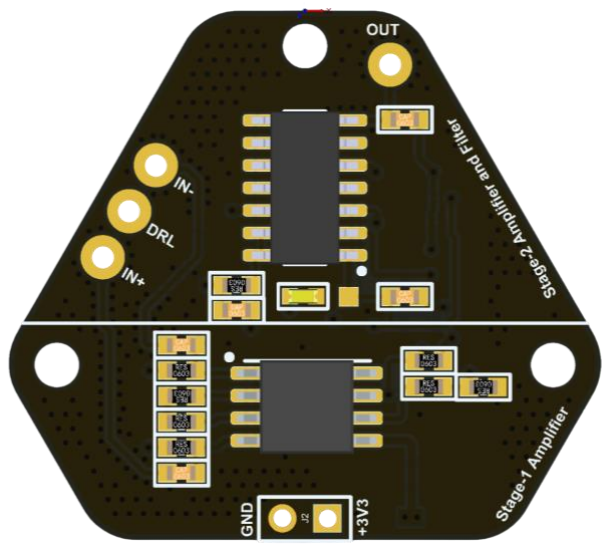
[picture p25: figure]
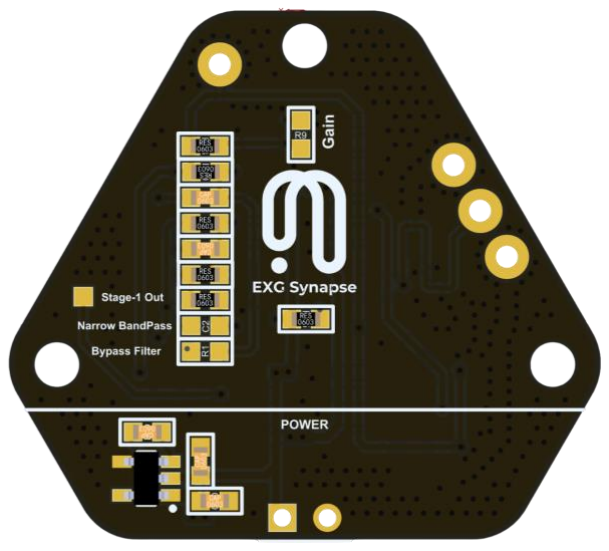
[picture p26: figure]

4 / 24 | SYNAPSE | Modified: 1/12/2023

## 3 The Board

### 3.1 Top View

### 2.1 Bottom View

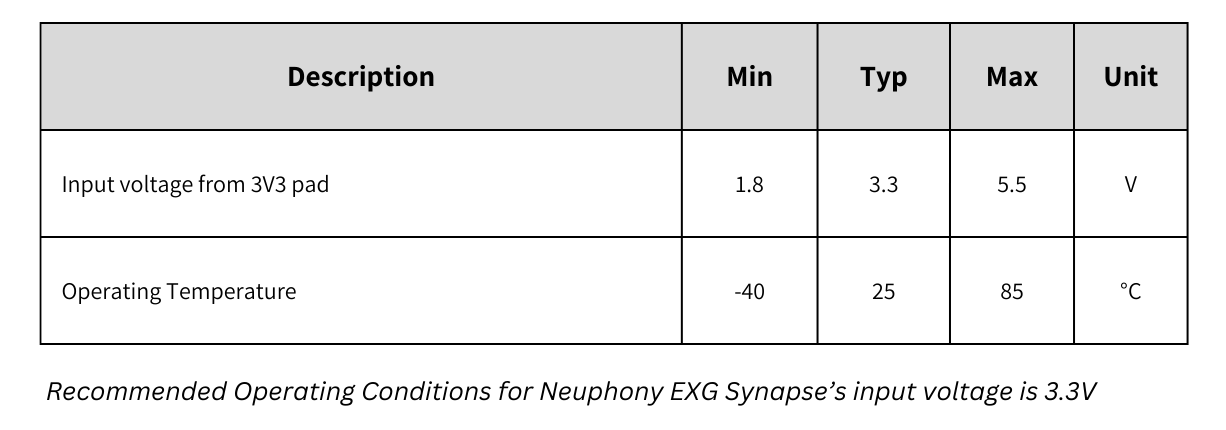
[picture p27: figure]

5 / 24 | SYNAPSE | Modified: 1/12/2023

## 4 Specifications

1. Input Voltage: 3.3V
2. Input Impedance: 20 GΩ
3. No. of channels: 1
4. Electrodes: 3
5. Compatible Hardware: Any ADC input
6. Biopotentials: ECG EMG, EOG, or EEG (configurable bandpass)

By default configured for a highpass cutoff of 1.6Hz and a lowpass cutoff of 47Hz and Gain 50

7. Dimensions: 30.0 x 33.0 mm

## 5 Absolute Maximum Ratings

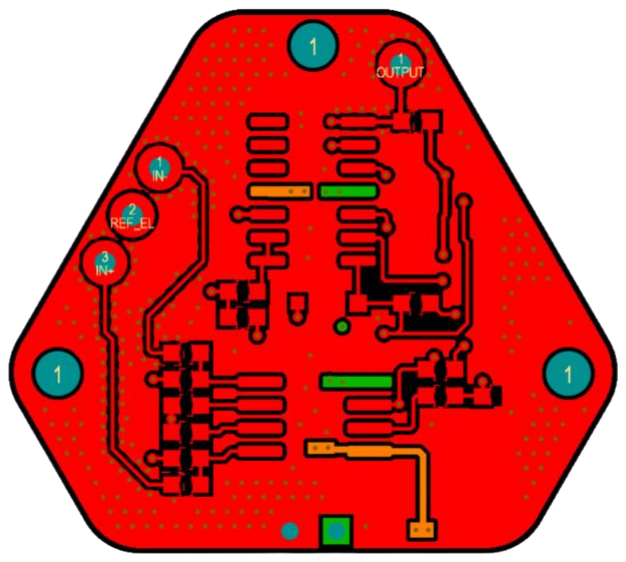
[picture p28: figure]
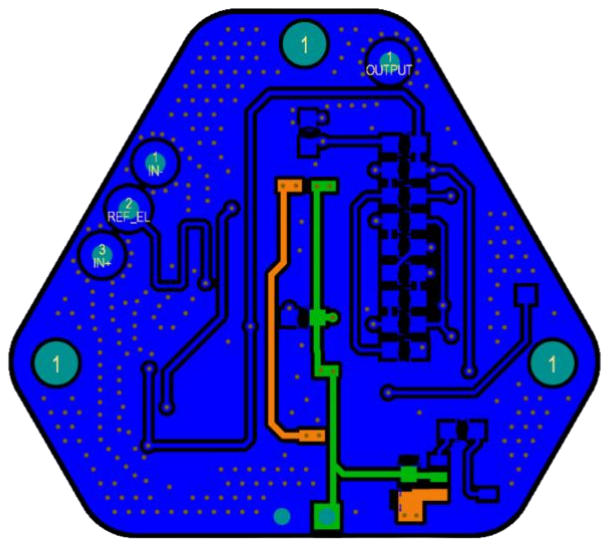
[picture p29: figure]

6 / 24 | SYNAPSE | Modified: 1/12/2023

## 6 Board Topology / Layers

### 6.1 Top Layer

### 6.2 Bottom Layer

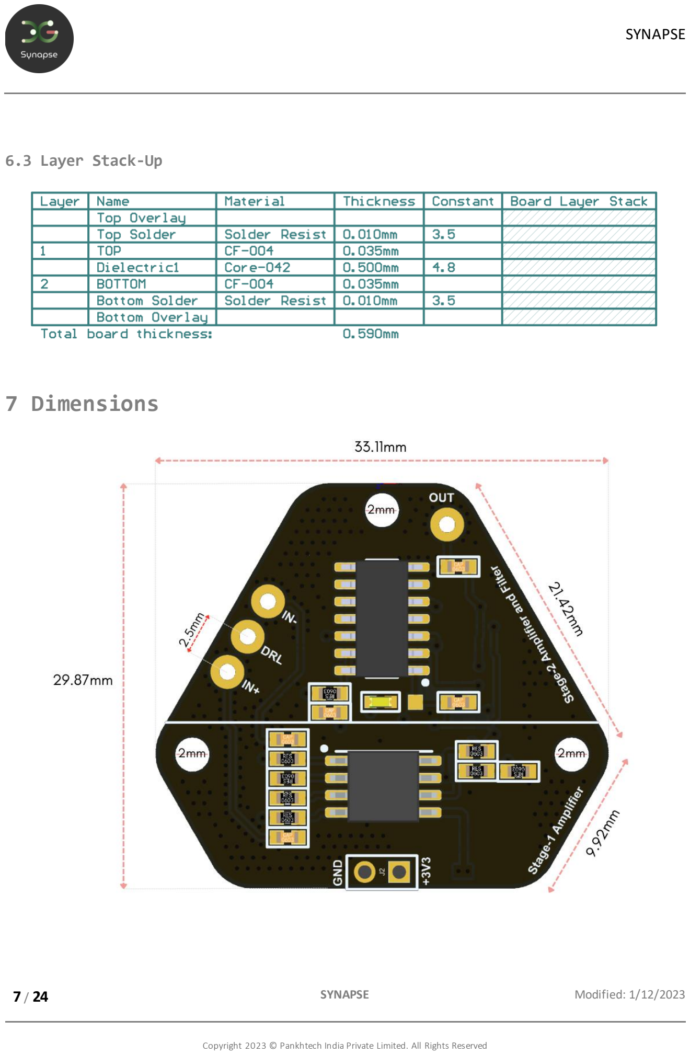
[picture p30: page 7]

7 / 24 | SYNAPSE | Modified: 1/12/2023

### 6.3 Layer Stack-Up

## 7 Dimensions

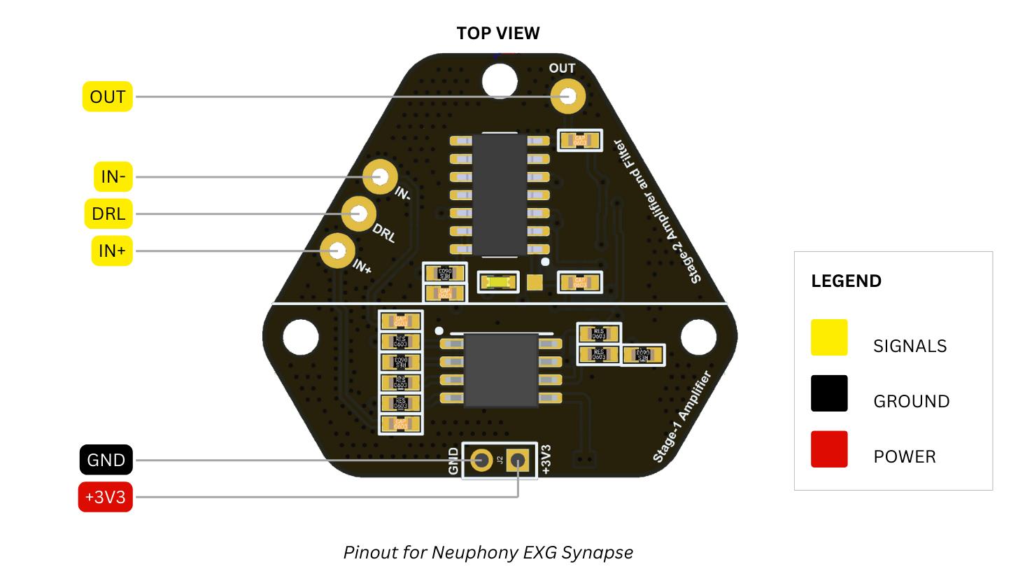
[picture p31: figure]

8 / 24 | SYNAPSE | Modified: 1/12/2023

## 8 Pinout

### 8.1 Pinout Diagram

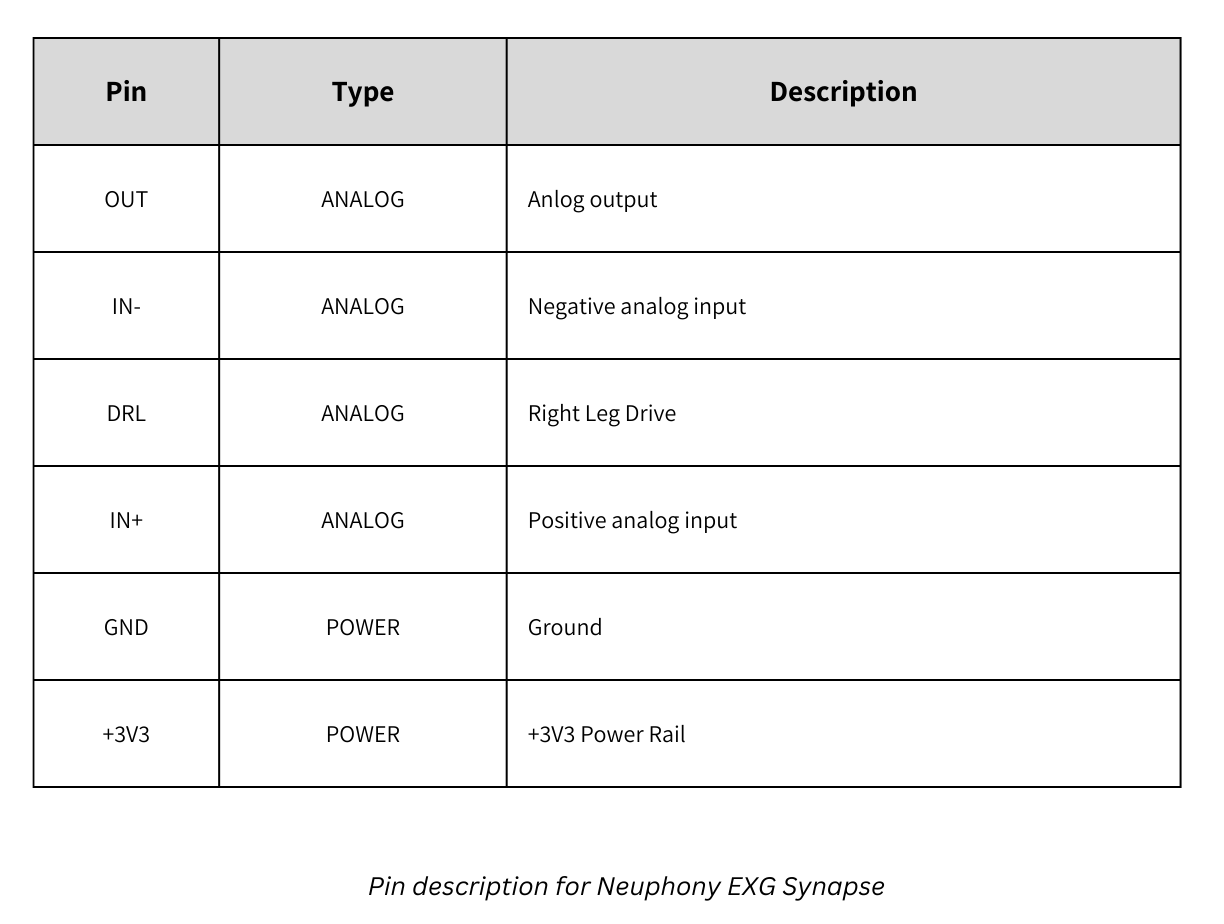
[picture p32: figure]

9 / 24 | SYNAPSE | Modified: 1/12/2023

### 8.1 Pin Description

## 9 Default Frequency Range

Default Frequency Range for input signals.

1. ECG Frequency Range: 0.5 - 40Hz
2. EMG Frequency Range: 75 - 150 Hz
3. EEG Frequency Range: 0.5 - 47.5 Hz
4. EOG Frequency Range: 0.5 - 15 Hz

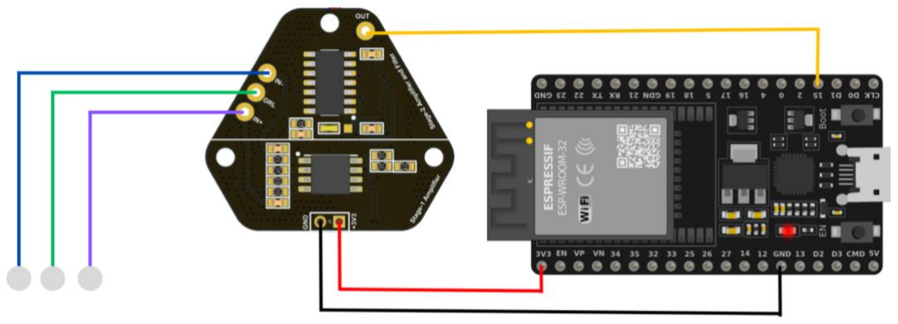
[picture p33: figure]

10 / 24 | SYNAPSE | Modified: 1/12/2023

## 10 Getting Started

- Requirements
Hardware: EXG Synapse, DOIT-ESP32-DEVKIT-V1, Jumper Wires
Software: Arduino IDE
- PCB Configuration: EXG Synapse has configuration options in terms of gain and bandpass filter bandwidth. The user can modify these values depending on the use case. Here is an image showing the resistor pad R9(for gain) and capacitor pad C2(for filter bandwidth).
- Connection with ESP32 EXG Synapse requires only three wires to connect to any MCU. 3V3 connects to the 3V3 pin on the ESP32 and GND to GND pin on the ESP32. The Output of EXG Synapse can be connected to any ADC pin of ESP32 and configured as an analog input to read the data.
- Installing the Library: We have developed a library intended for integration into your code, facilitating the acquisition of EXG signals. Install the required library available on our Github repository. (https://github.com/Neuphony/EXG-Synapse)
- Flashing Code on ESP32: To flash the required code on ESP32, you need to install Arduino IDE and setup for flashing to an ESP32. You can follow this guide (https://espressif-docs.readthedocs-hosted.com/projects/arduino-esp32/en/latest/installing.html) if you don’t find your board listed in Arduino. Once your board is added to Arduino, you can go to our GitHub repository, (https://github.com/Neuphony/EXG-Synapse) here you will find all the necessary files for acquiring the data using EXG Synapse.

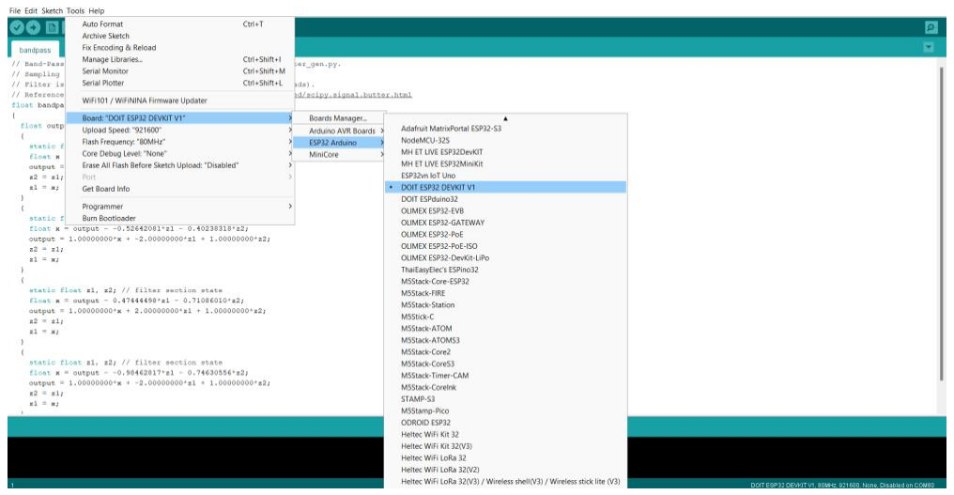
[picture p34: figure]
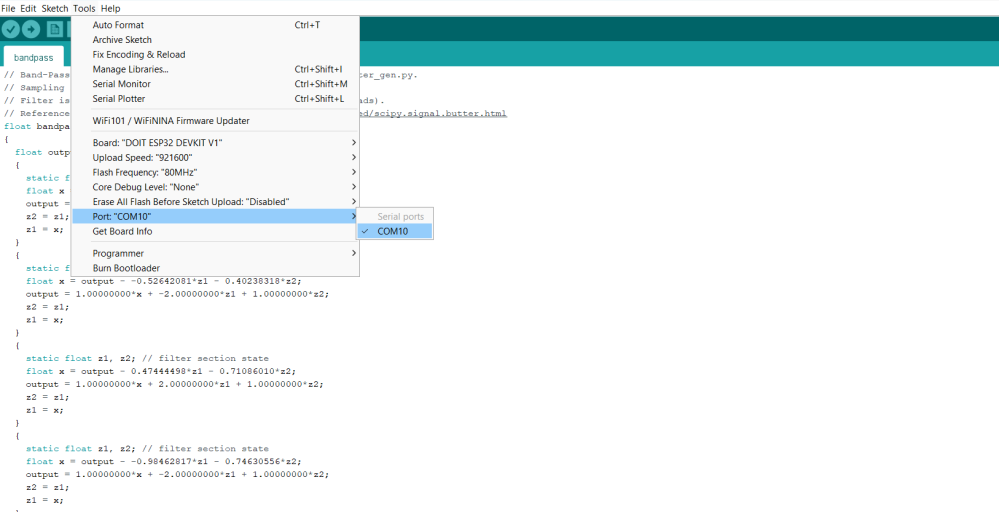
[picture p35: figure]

11 / 24 | SYNAPSE | Modified: 1/12/2023

Navigate to the folder of your choice (serial or BLE), and download the required .ino (EEG, ECG, EMG, EOG). Now compile and upload the code on your board.

Please follow the screenshots given below.

Board Selection:

COM Port Selection:

- Skin Preparation: Before placing the electrode, skin surface must be cleaned with an alcohol based wet wipe and then Nuprep Gel can be used to enhance the signal quality as it reduces the

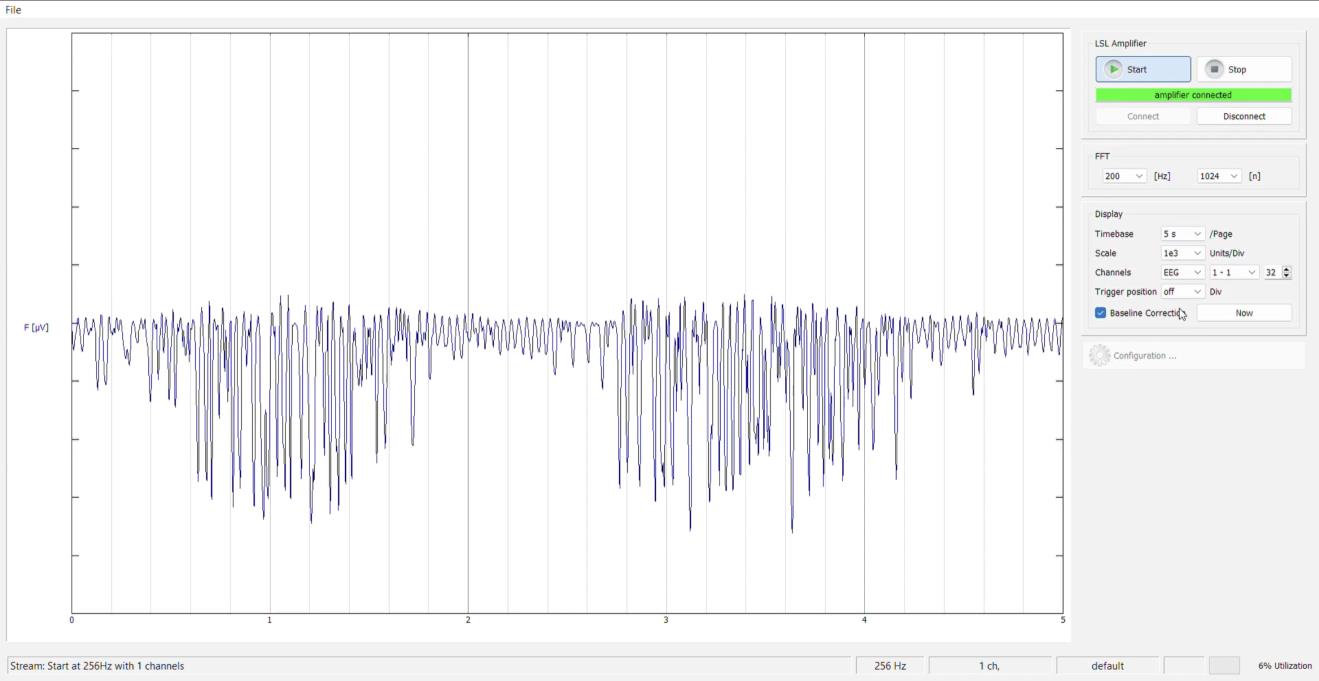
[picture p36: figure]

12 / 24 | SYNAPSE | Modified: 1/12/2023

skin impedance. You can follow this (https://www.youtube.com/watch?v=qQSClWIYUwM) guide on how to use Nuprep Gel while preparing for data acquisition.

- Data Visualization: Serial: The Lab Streaming Layer (LSL) is a system designed for real-time data streaming and recording. We have provided a python script located in the GitHub repository (https://github.com/Neuphony/EXG-Synapse) used to read the data from serial and create an LSL stream. The stream created by the script can be easily visualized using a LSL-compatible software such as BrainVision LSL Viewer. (https://pressrelease.brainproducts.com/lsl-viewer/) It can be downloaded for free using this link. (https://www.brainproducts.com/downloads/more-software/#utilities)

BLE: If flashed with the code provided under software\Arduino\ble, ESP32 will stream data continously over BLE. You can create a client-side interface to read this data and use it for further applications.

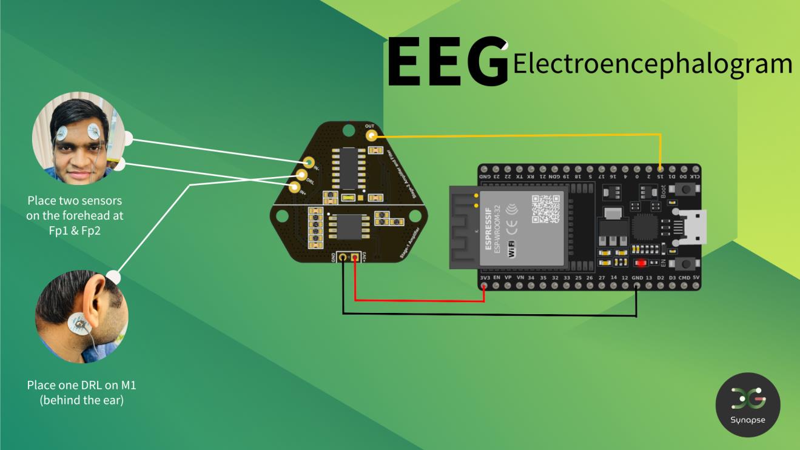
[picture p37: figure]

13 / 24 | SYNAPSE | Modified: 1/12/2023

## 11 EXG Circuits

### 11.1 EEG

What is EEG:
EEG stands for electroencephalography, which is a non-invasive technique used to measure and record electrical activity in the brain. It involves placing electrodes on the scalp to detect and amplify the electrical signals produced by the brain. These signals, known as brainwaves, can provide insights into brain function and activity.

Electrode Placement: Check above image for correct electrode placement

Data Visualization:
The Lab Streaming Layer (LSL) is a system designed for real-time data streaming and recording. We have provided a python script for EEG located in the GitHub repository (https://github.com/Neuphony/EXG-Synapse) used to read the data from serial and create an LSL stream. Following is a screenshot of EEG data captured with Synapse.

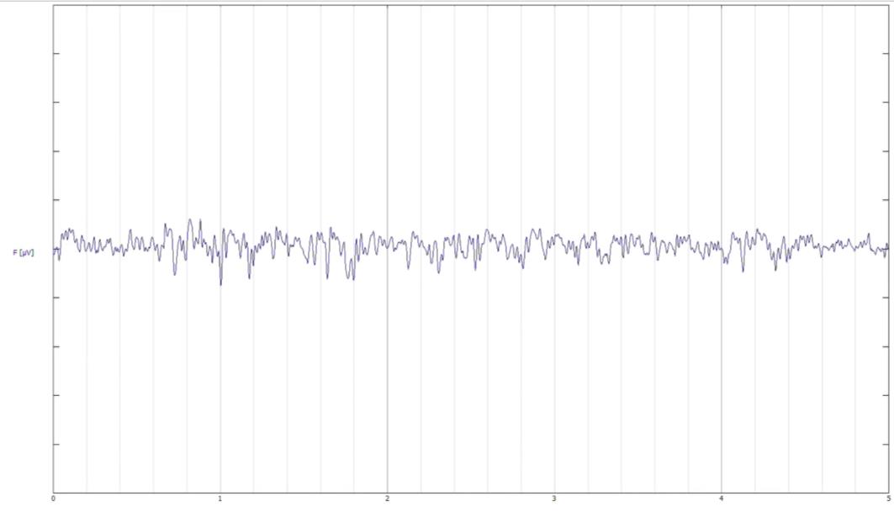
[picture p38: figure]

14 / 24 | SYNAPSE | Modified: 1/12/2023

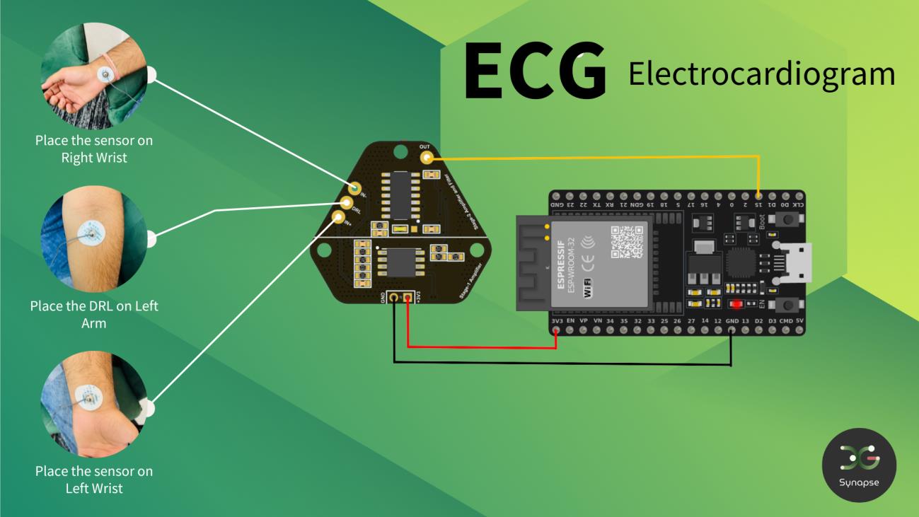
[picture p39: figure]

15 / 24 | SYNAPSE | Modified: 1/12/2023

### 11.2 ECG

What is ECG:
ECG stands for Electrocardiogram. It is a medical test that measures and records the electrical activity of the heart. The ECG helps in diagnosing various heart conditions and evaluating the heart's overall health.

Electrode Placement: Check above image for correct electrode placement

Data Visualization:
The Lab Streaming Layer (LSL) is a system designed for real-time data streaming and recording. We have provided a python script for ECG located in the GitHub repository (https://github.com/Neuphony/EXG-Synapse) used to read the data from serial and create an LSL stream. Following is a screenshot of ECG data captured with Synapse.

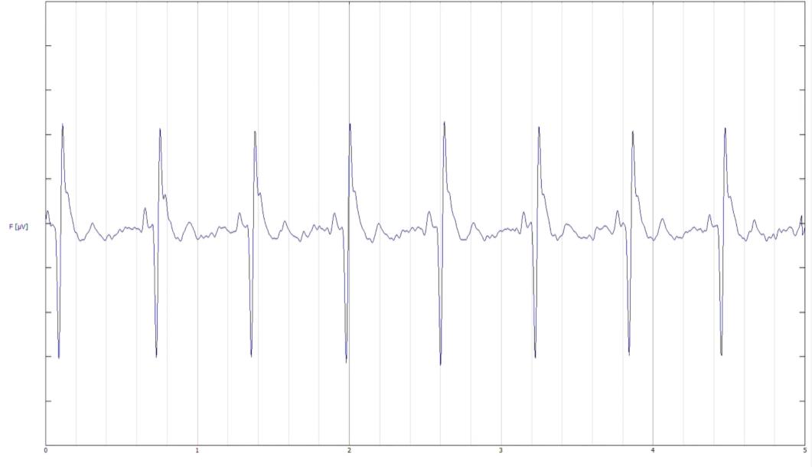
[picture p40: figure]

16 / 24 | SYNAPSE | Modified: 1/12/2023

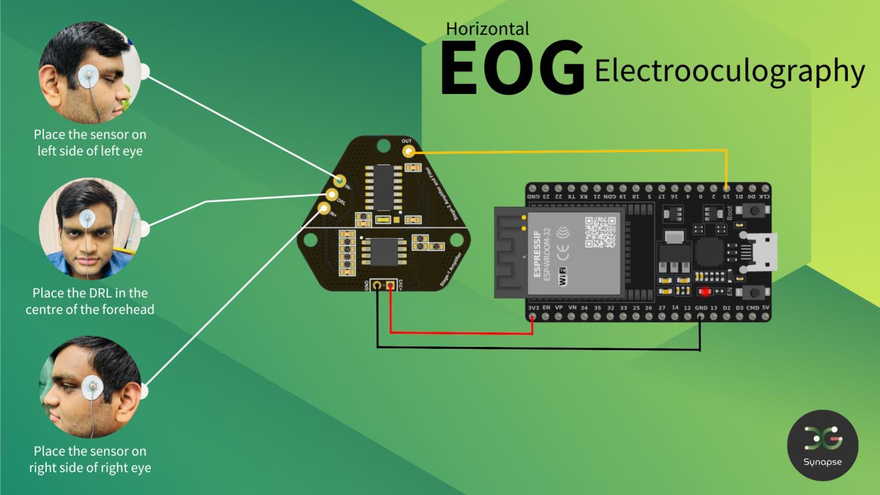
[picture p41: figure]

17 / 24 | SYNAPSE | Modified: 1/12/2023

### 11.3 EOG

What is EOG:
EOG stands for "Electrooculography." It refers to a technique used to measure and record the electrical activity of the muscles that control eye movements. This technique is often used in medical and research settings to study eye movements and diagnose certain eye disorders.

Horizontal Eye Movements

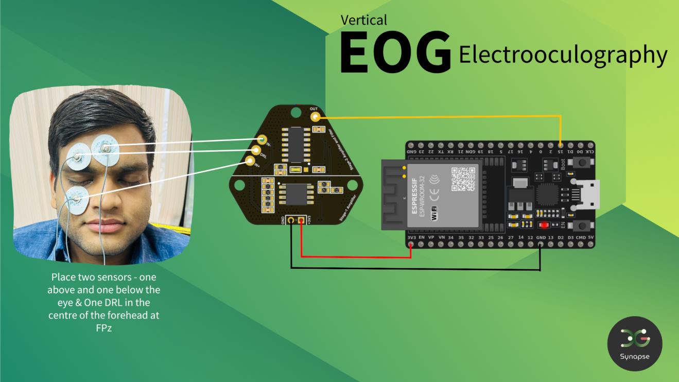
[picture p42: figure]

18 / 24 | SYNAPSE | Modified: 1/12/2023

Vertical Eye Movements

Electrode Placement: Check above image for correct electrode placement

Data Visualization:
The Lab Streaming Layer (LSL) is a system designed for real-time data streaming and recording. We have provided a python script for EOG located in the GitHub repository (https://github.com/Neuphony/EXG-Synapse) used to read the data from serial and create an LSL stream. Following is a screenshot of ECG data captured with Synapse.

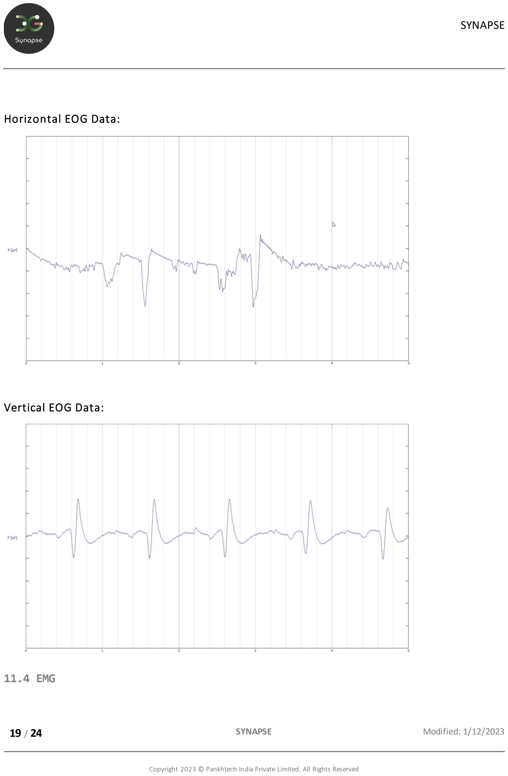
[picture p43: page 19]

19 / 24 | SYNAPSE | Modified: 1/12/2023

Horizontal EOG Data:

Vertical EOG Data:

### 11.4 EMG

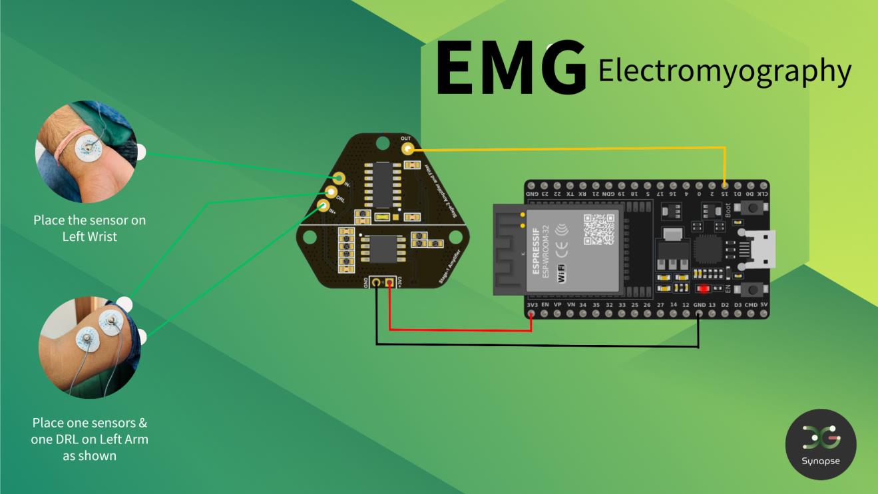
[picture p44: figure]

20 / 24 | SYNAPSE | Modified: 1/12/2023

What is EMG: EMG stands for Electromyography. It is a technique used to measure and record the electrical activity produced by skeletal muscles. This information can be useful in various applications, such as studying muscle function, diagnosing neuromuscular disorders, and monitoring muscle activity during physical therapy or athletic training.

Electrode Placement: Check above image for correct electrode placement

Data Visualization: The Lab Streaming Layer (LSL) is a system designed for real-time data streaming and recording. We have provided a python script for EMG located in the GitHub repository (https://github.com/Neuphony/EXG-Synapse) used to read the data from serial and create an LSL stream. Following is a screenshot of ECG data captured with Synapse.

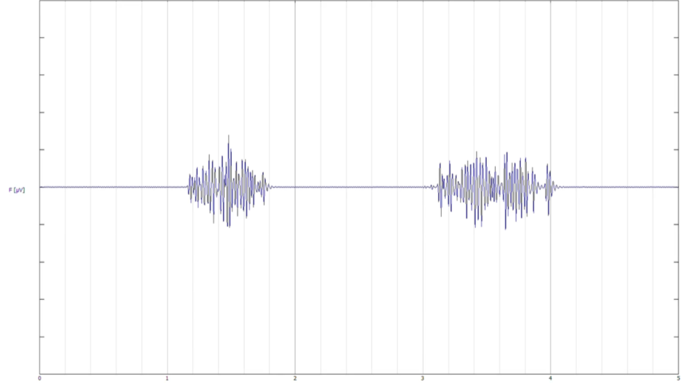
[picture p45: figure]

21 / 24 | SYNAPSE | Modified: 1/12/2023

## 12 Possible Configurations

### 12.1 Configurable Gain

Default Gain Configuration: The default gain in the first stage amplification is set to 50. This value is established to provide a baseline performance in typical use cases.

User-Configurable Gain: To accommodate diverse application scenarios, users have the flexibility to configure the gain according to their specific requirements. This customization is achieved by placing a desired resistance at the designated location, R9.

Gain Formula: The gain (G) is determined by the following formula: G = R9/10k
Where:
- G is the gain of the amplification stage.
- R9 is the resistance value placed at the configurable location.
- 10k is the resistance at the inverting input.

By manipulating the value of R9, users can finely tune the amplification gain to suit the unique demands of their intended application. This level of customization ensures optimal performance and versatility in the amplification process.

22 / 24 | SYNAPSE | Modified: 1/12/2023

### 13.2 Bandpass Filters Bandwidth

Default Bandpass Filter Configuration: The bandpass filter is implemented as a 2nd order Butterworth filter, offering a default high pass frequency of 1.6Hz and a default low pass frequency of 48.228Hz. These preset values are selected to cover a wide range of applications effectively.

User-Configurable Low Pass Frequency: For users desiring customization, the bandpass filter allows the adjustment of the low pass frequency. This is accomplished by manipulating the capacitance of C2, a capacitor placed in parallel with C3.

Capacitance Options: To simplify user adjustments, a set of capacitances is provided: 0.5uF, 3nF, 0.2uF, and 0.1uF. Each of these capacitances results in a specific low pass cutoff frequency when combined with C3 in parallel.

- A capacitance of 0.5uF yields a low pass cutoff frequency of 19.6Hz.
- A capacitance of 3nF results in a low pass cutoff frequency of 47.52Hz.
- A capacitance of 0.2uF leads to a low pass cutoff frequency of 27.84Hz.
- A capacitance of 0.1uF produces a low pass cutoff frequency of 34.10Hz.

The bandpass filter design employs the characteristics of a 2nd order Butterworth filter, ensuring a smooth frequency response within the specified range

### 12.3 Bypass Bandpass Filter

Bypass Option for Direct Data Access: For enhanced flexibility, users have the option to bypass the bandpass filter and access data directly. This bypass feature allows users to streamline their signal processing by circumventing the filtering stage when it is not required for their specific application.

Activation of Bypass: To enable direct data access without bandpass filtering, users can engage the bypass option. This can be achieved through a designated control or switch in the circuit.

Streamlined Signal Path: By choosing to bypass the bandpass filter, users can obtain raw data without undergoing the frequency filtering process. This is particularly useful when a specific application demands unaltered or unfiltered signal information.

23 / 24 | SYNAPSE | Modified: 1/12/2023

Versatile Integration: The bypass capability is designed to seamlessly integrate with the
bandpass filter circuit, offering users the flexibility to tailor the signal processing approach based on their unique requirements. Whether opting for the bandpass filter or the direct data path, users can adapt the system to suit the demands of their specific applications.

## 13 Reference Documents

Ref | Link
Synapse Github Repository | https://github.com/Neuphony/EXG-Synapse
ESP32 Installation Guide | https://espressif-docs.readthedocs-hosted.com/projects/arduino-esp32/en/latest/installing.html\ (https://espressif-docs.readthedocs-hosted.com/projects/arduino-esp32/en/latest/installing.html/)
Nuprep Gel Application Demo | https://www.youtube.com/watch?v=qQSClWIYUwM&t=76s
BrainVision LSL Viewer | https://pressrelease.brainproducts.com/lsl-viewer/
Download BrainVision | https://www.brainproducts.com/downloads/more-software/#utilities (https://www.brainproducts.com/downloads/more-software/#utilities)
OSHWA Certification | https://certification.oshwa.org/in000049.html

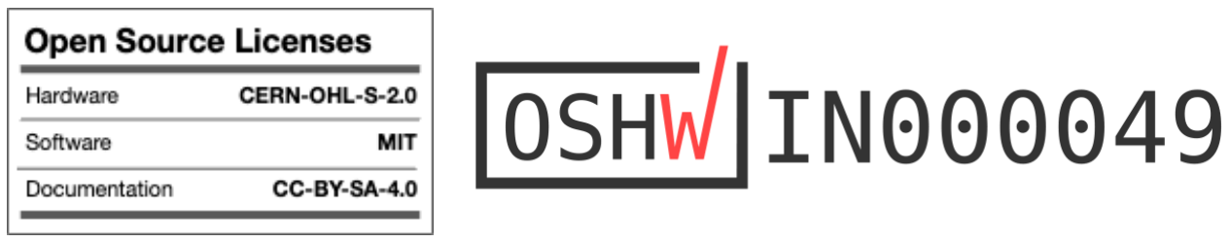
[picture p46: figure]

24 / 24 | SYNAPSE | Modified: 1/12/2023

## 14 Certification

### 14.3 Certification

### 14.3 Licenses

Item | ID
Hardware | CERN-OHL-S2.0
Software | MIT
Documentation | CC BY-SA 4.0

## 15 Company Information

Company Name | Address
Pankhtech India Pvt Ltd | Company ID: U33309DL2020PTC371693 A-545, Urbtech Trade Centre, Sector 132, Noida, 201303, India GSTIN 07AAJCB3585D1ZO

## 16 Change Log

Date | Revision | Changes
1/12/2023 | 1 | First Release
8/12/2023 | 2 | Added OSHWA Certification

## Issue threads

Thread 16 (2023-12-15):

issue regarding #include circularbuffer.h

mrinmox, 2023-12-15:
the file is not included in the src file. Due to this issue the code isn't uploaded in the NodeMCU board .

Closed 2023-12-18.

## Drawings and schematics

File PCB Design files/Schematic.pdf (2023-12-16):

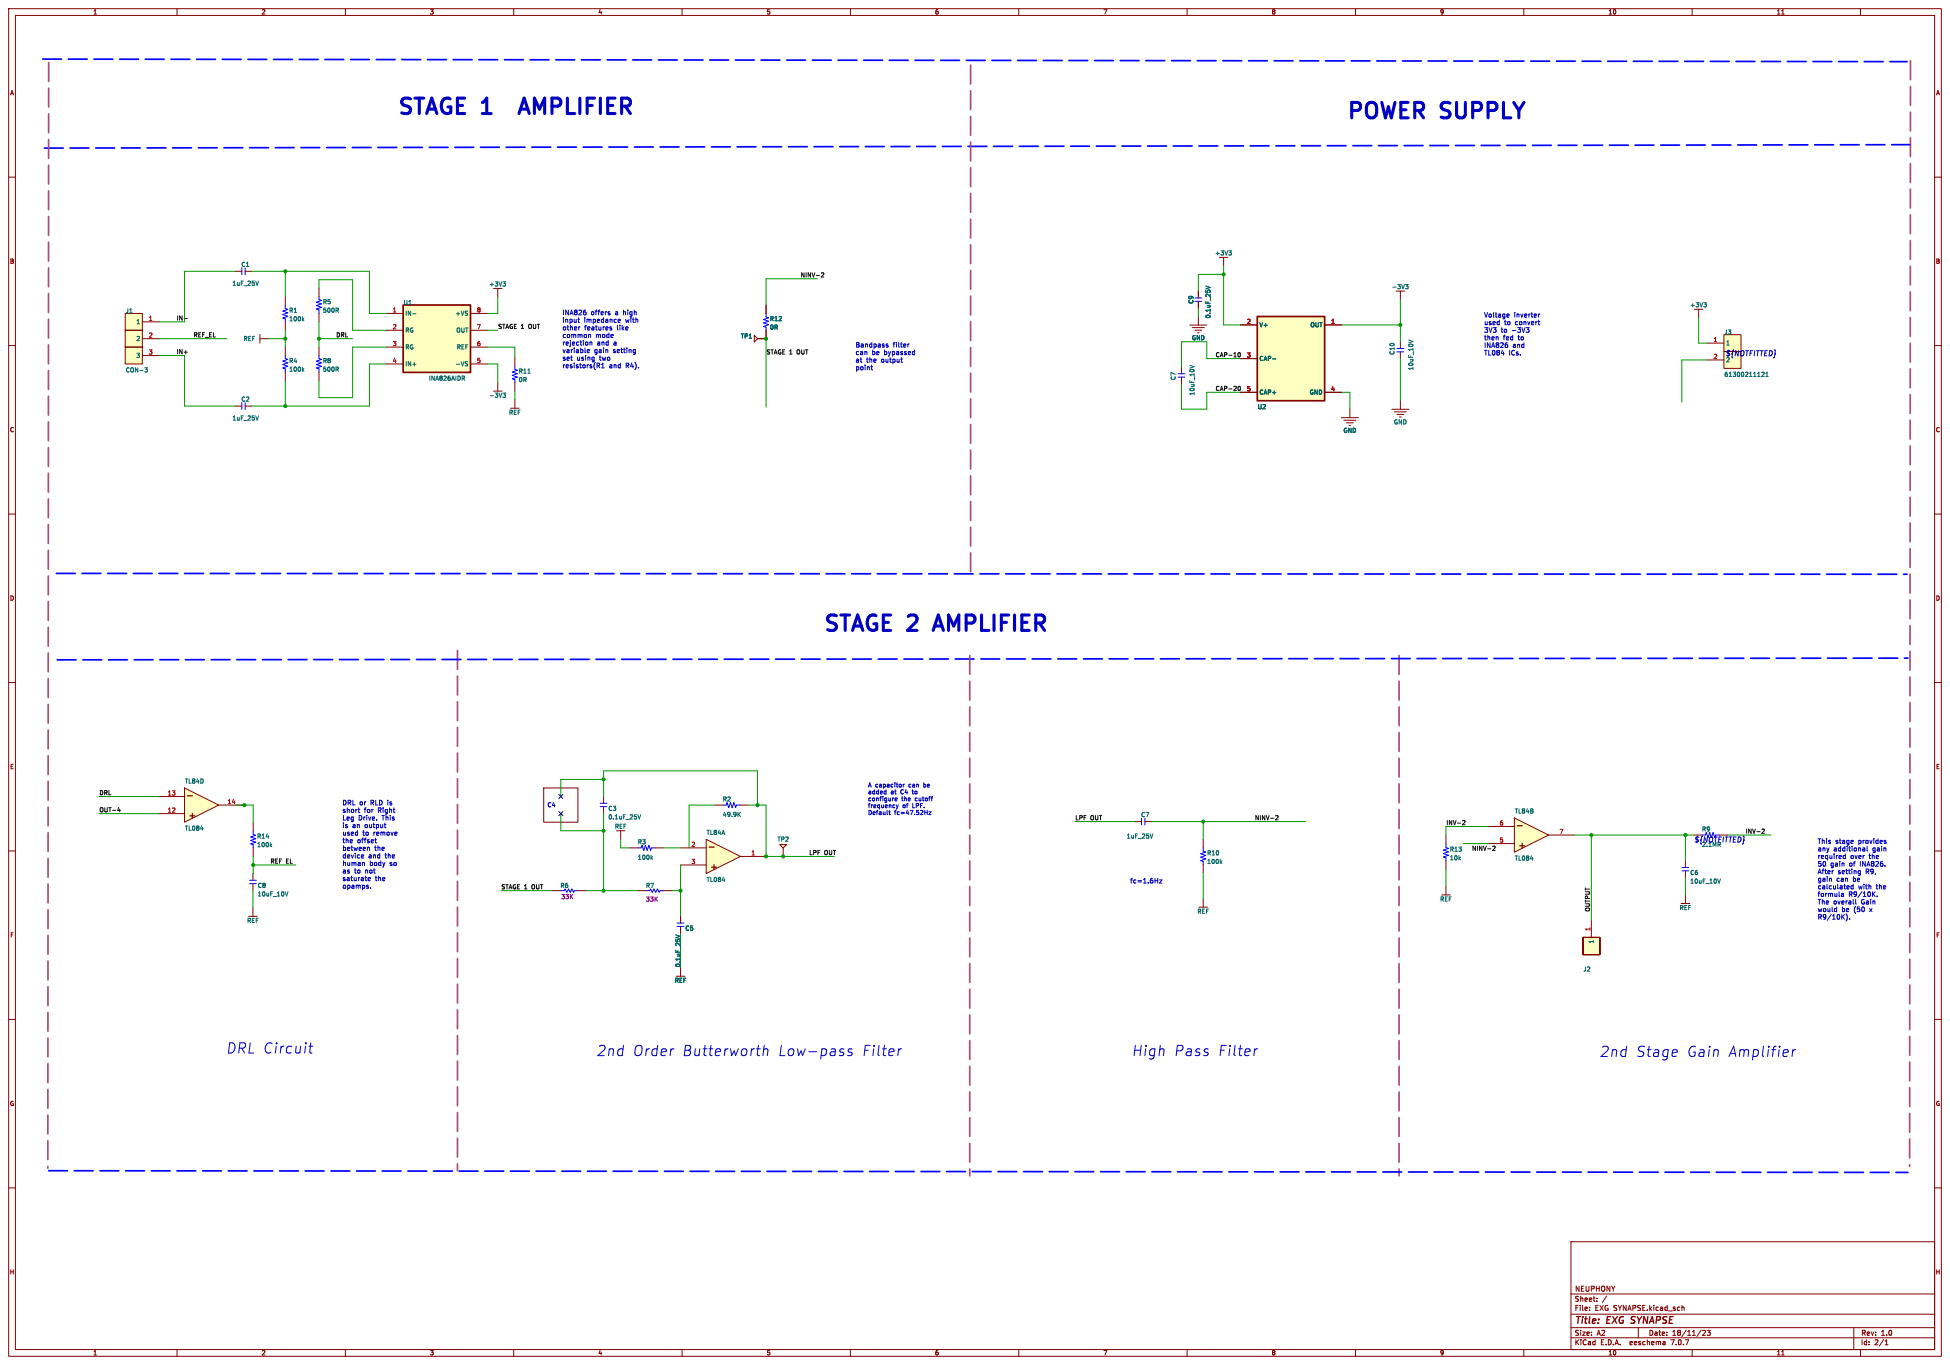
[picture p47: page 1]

Voltage inverter used to convert 3V3 to -3V3

Bandpass filter can be bypassed

fc=1.6Hz DRL or RLD is
short for Right
Leg Drive. This
is an output used to remove

the offset between the

required over the
50 gain of INA826. After setting R9,

File: EXG SYNAPSE.kicad_sch Sheet: / NEUPHONY

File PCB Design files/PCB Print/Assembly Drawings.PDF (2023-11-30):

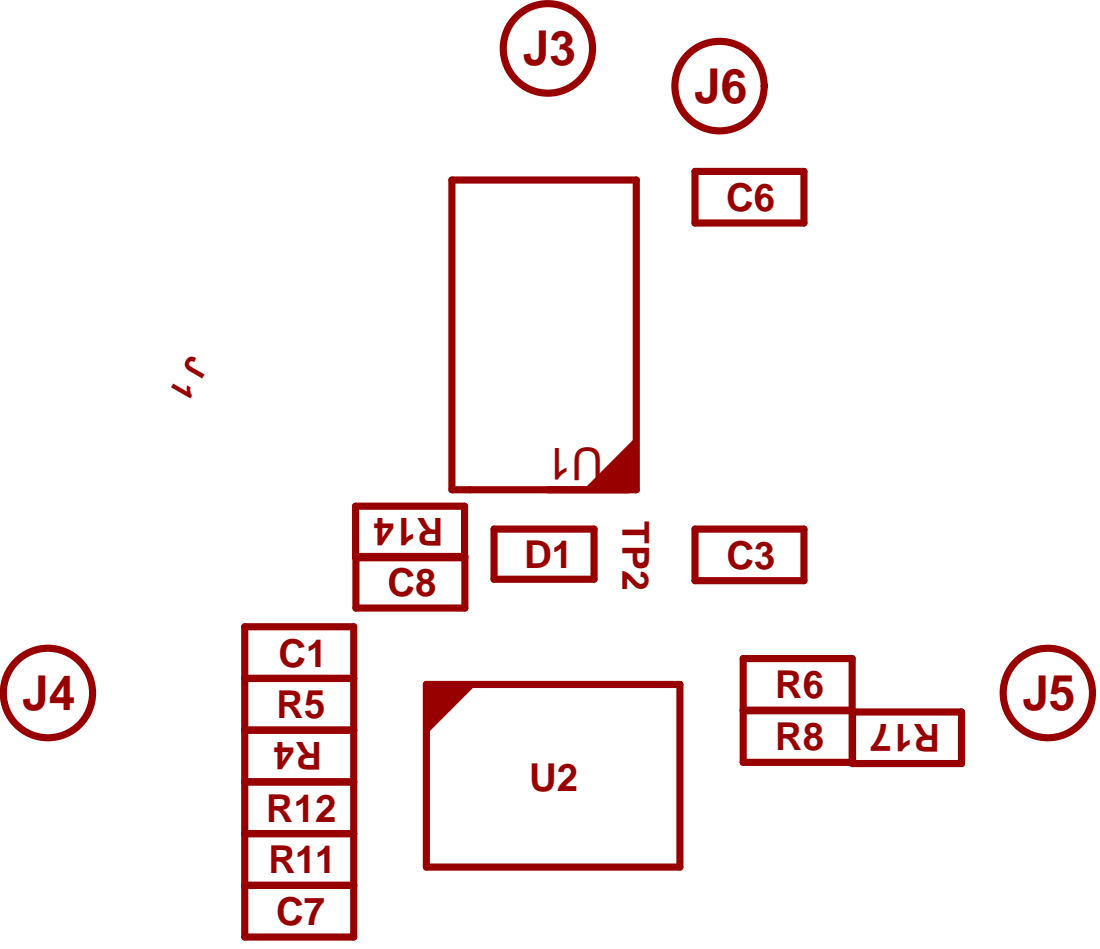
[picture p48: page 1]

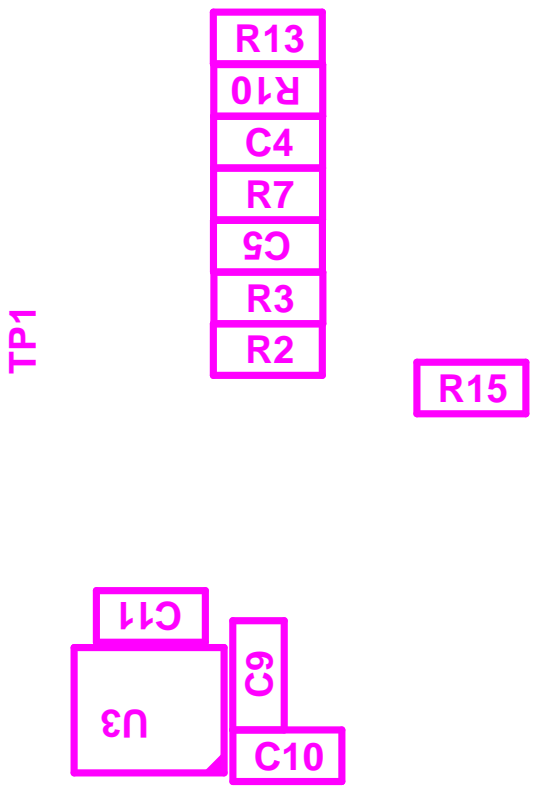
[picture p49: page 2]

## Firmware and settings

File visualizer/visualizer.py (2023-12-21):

from PyQt5.QtWidgets import QApplication, QDialog, QVBoxLayout, QHBoxLayout, QLabel, QComboBox, QSpinBox, QPushButton, QMainWindow
from PyQt5.QtCore import Qt, QThread, pyqtSignal
import pyqtgraph as pg
import numpy as np
import serial
from collections import deque
from scipy.signal import iirfilter
import sys
import serial.tools.list_ports
from PyQt5.QtGui import QIcon
 
# Configuration Dialog Class
class ConfigDialog(QDialog):
    def __init__(self):
        super().__init__()
        self.setWindowFlags(self.windowFlags() & ~Qt.WindowContextHelpButtonHint)
        self.setWindowTitle('Configuration')
        icon_path = "Resources/Icon.png"  # Ensure this path is correct
        if icon_path:
            self.setWindowIcon(QIcon(icon_path))
 
        self.setFixedSize(370, 300)  # Adjust size as needed
 
        layout = QVBoxLayout(self)
 
        # COM Port Selection
        com_layout = QHBoxLayout()
        self.com_label = QLabel('Select COM Port:', self)
        com_layout.addWidget(self.com_label)
        self.com_select = QComboBox(self)
        self.com_select.setFixedSize(100, 25)  # Set fixed size for COM port selection
        self.populate_com_ports()
        com_layout.addWidget(self.com_select)
        layout.addLayout(com_layout)
 
        # Amplitude Setting
        amp_layout = QHBoxLayout()
        self.amp_label = QLabel('Set Amplitude Range:', self)
        amp_layout.addWidget(self.amp_label)
        self.amp_select = QSpinBox(self)
        self.amp_select.setFixedSize(100, 25)  # Set fixed size for Amplitude selection
        self.amp_select.setRange(-1000, 1000)
        self.amp_select.setValue(500)
        amp_layout.addWidget(self.amp_select)
        layout.addLayout(amp_layout)
 
        # Number of Channels Setting
        ch_layout = QHBoxLayout()
        self.ch_label = QLabel('Number of Channels:', self)
        ch_layout.addWidget(self.ch_label)
        self.ch_select = QSpinBox(self)
        self.ch_select.setFixedSize(100, 25)  # Set fixed size for Channel selection
        self.ch_select.setRange(1, 10)
        self.ch_select.setValue(1)
        ch_layout.addWidget(self.ch_select)
        layout.addLayout(ch_layout)
 
        # Number of Seconds of Data Setting
        sec_layout = QHBoxLayout()
        self.sec_label = QLabel('Data View Duration (Seconds):', self)
        sec_layout.addWidget(self.sec_label)
        self.sec_select = QSpinBox(self)
        self.sec_select.setFixedSize(100, 25)  # Set fixed size for Seconds selection
        self.sec_select.setRange(5, 20)
        self.sec_select.setValue(5)
        sec_layout.addWidget(self.sec_select)
        layout.addLayout(sec_layout)
 
        # Buttons
        button_layout = QHBoxLayout()
        self.ok_button = QPushButton('OK', self)
        self.ok_button.setFixedSize(100, 30)  # Set fixed size for OK button
        self.ok_button.clicked.connect(self.accept)
        button_layout.addWidget(self.ok_button)
 
        layout.addLayout(button_layout)
 
    def populate_com_ports(self):
        com_ports = serial.tools.list_ports.comports()
        available_ports = [port.device for port in com_ports]
        self.com_select.addItems(available_ports)
 
    def get_config(self):
        return self.com_select.currentText(), self.amp_select.value(), self.ch_select.value(), self.sec_select.value()
 
 
class LiveFilter:
    def process(self, x):
        if np.isnan(x):
            return x
        return self._process(x)
 
    def __call__(self, x):
        return self.process(x)
 
    def _process(self, x):
        raise NotImplementedError("Derived class must implement _process")
 
class LiveLFilter(LiveFilter):
    def __init__(self, b, a):
        self.b = b
        self.a = a
        self._xs = deque([0] * len(b), maxlen=len(b))
        self._ys = deque([0] * (len(a) - 1), maxlen=len(a) - 1)
 
    def _process(self, x):
        self._xs.appendleft(x)
        y = np.dot(self.b, self._xs) - np.dot(self.a[1:], self._ys)
        y = y / self.a[0]
        self._ys.appendleft(y)
        return y
 
class LiveSosFilter(LiveFilter):
    def __init__(self, sos):
        self.sos = sos
        self.n_sections = sos.shape[0]
        self.state = np.zeros((self.n_sections, 2))
 
    def _process(self, x):
        for s in range(self.n_sections):
            b0, b1, b2, a0, a1, a2 = self.sos[s, :]
            y = b0 * x + self.state[s, 0]
            self.state[s, 0] = b1 * x - a1 * y + self.state[s, 1]
            self.state[s, 1] = b2 * x - a2 * y
            x = y
        return y
 
class SerialThread(QThread):
    data_ready = pyqtSignal(str)
 
    def __init__(self, port, baudrate=115200, timeout=1):
        super().__init__()
        self.ser_port = serial.Serial(port, baudrate=baudrate, timeout=timeout)
 
    def run(self):
        while True:
            data = self.ser_port.readline().decode().strip()
            if data:
                self.data_ready.emit(data)
 
# SerialPlotter class with modifications for amplitude
class SerialPlotter(pg.GraphicsLayoutWidget):
    def __init__(self, channels, data_length, port, amplitude, baudrate=115200, timeout=1, bandpass_freq=[1, 45], notch_freq=50, sample_rate=250):
        super().__init__()
        self.channels = channels
        self.num_channels = len(channels)
        self.data_length = data_length
        self.data = [np.zeros(data_length) for _ in range(self.num_channels)]  # Independent data storage for each channel
        self.curves = []
        self.init_ui(amplitude)
        self.com = port
        self.baudrate = baudrate
        self.ser_timeout = timeout
        self.serial_thread = SerialThread(port, baudrate, timeout)
        self.serial_thread.data_ready.connect(self.update)
        self.serial_thread.start()
        self.bp = bandpass_freq
        self.notch = notch_freq
        self.fs = sample_rate

        # Filters for each channel (if needed)
        self.filters = [self.create_filters() for _ in range(self.num_channels)]

 
    def create_filters(self):
        b, a = iirfilter(5, Wn=self.bp, fs=self.fs, btype="bandpass", ftype="butter")
        live_lfilter_bp = LiveLFilter(b, a)
        q, p = iirfilter(5, [self.notch - 1.5, self.notch + 1.5], fs=self.fs, btype="bandstop", ftype="butter")
        live_lfilter_notch = LiveLFilter(q, p)
        return (live_lfilter_bp, live_lfilter_notch)
 

    def init_ui(self, amplitude):
        for i, channel in enumerate(self.channels):
            p = self.addPlot(title=channel)
            p.showGrid(x=True, y=True)
            p.setYRange(-amplitude, amplitude, padding=0)
            curve=p.plot(pen='g')
            self.curves.append(curve)
            if i < self.num_channels - 1:
                self.nextRow()
 
    def update(self, data):
        if data != '\r\n' and data != '' and data != '\n':
            try:   
                data_values = [float(value) for value in data.split("\t")]
                print(data_values)
                if len(data_values) != self.num_channels:
                    raise ValueError("Data length mismatch")

                for i in range(self.num_channels):
                    filtered_value = self.filters[i][1](self.filters[i][0](data_values[i]))  # Apply filters
                    self.data[i] = np.roll(self.data[i], -1)
                    self.data[i][-1] = filtered_value
                    self.curves[i].setData(self.data[i])
            except ValueError as e:
                print(f"Error processing data: {e}")
                
 
 
def create_channel_list(num_channels):
    """
    Creates a list of channel names in sequence.
 
    Args:
    num_channels (int): The number of channels to create.
 
    Returns:
    list: A list of channel names.
    """
    return [f"Channel {i+1}" for i in range(num_channels)]
 
 
# Main application setup
if __name__ == '__main__':
    app = QApplication(sys.argv)
 
    config_dialog = ConfigDialog()
    if config_dialog.exec_() == QDialog.Accepted:
        com_port, amplitude, no_of_channels, duration = config_dialog.get_config()
        channels = create_channel_list(no_of_channels)
        viewer = SerialPlotter(channels, duration*250, com_port, amplitude)
        viewer.show()
        sys.exit(app.exec_())

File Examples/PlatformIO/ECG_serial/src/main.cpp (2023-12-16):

#include "Arduino.h"
#include "synapse.h"
#include "synapse_ble.h"

const int sensorPin = 15; // Analog input pin
unsigned long previousMillis = 0; // Variable to store the last time a sample was taken
unsigned long interval = 4; // Interval between samples in milliseconds (1000 ms / 250 samples). Change as per requirement

synapse exg_synapse;

void setup(){
  Serial.begin(115200);
}

void loop(){ 
  unsigned long currentMillis = millis(); // Get the current time in milliseconds
  
  if (currentMillis - previousMillis >= interval) {
    previousMillis = currentMillis; // Save the current time as the last time a sample was taken
    float sensorValue = analogRead(sensorPin); // Read the sensor value
    float filters_out = exg_synapse.apply_ECG_filters(sensorValue); // generate output after applying filters
    Serial.println(filters_out);
  }
}

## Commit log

2023-11-30 Initial commit (#5)
    [INSTRU-TR.csv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]
2023-12-21 Visualizer multiple channel bug resolved
    [visualizer.py]
